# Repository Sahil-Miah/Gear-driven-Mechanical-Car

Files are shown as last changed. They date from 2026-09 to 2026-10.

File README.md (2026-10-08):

# Gear-Driven Return-to-Start Car

A front-wheel-drive car that drives down a lane to a wall, reverses, and comes back to stop where it started. It has no microcontroller. The reversing is done with a DPDT switch, and the stopping is done with a gear train and a microswitch.

This was a Year 1 group project at Manchester Metropolitan University.

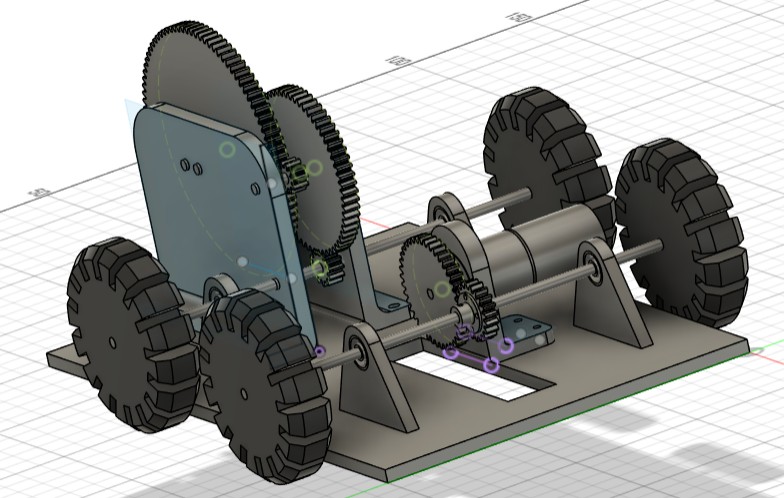
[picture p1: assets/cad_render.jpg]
CAD assembly


## Demo

[Demo video](./assets/demo.mp4). 

The car goes down a taped lane to a wooden wall, reverses, and stops on a target mat.

## How it works

### Drive

The motor is a 6V DC motor that runs at 35 RPM with no load. A 40-tooth gear on the motor meshes with a 20-tooth gear on the front axle, so the front axle turns at 70 RPM. This gives up some torque to gain speed. The rear axle isn't driven. It just turns as the car rolls.

### Reversing

A DPDT switch swaps which way the motor is connected to the battery, which makes the motor turn the other way. When the front of the car hits the wall, the front switch is hit and the motor reverses, so the car drives back. A separate on/off switch controls the power, and there is a fuse in the circuit for safety.

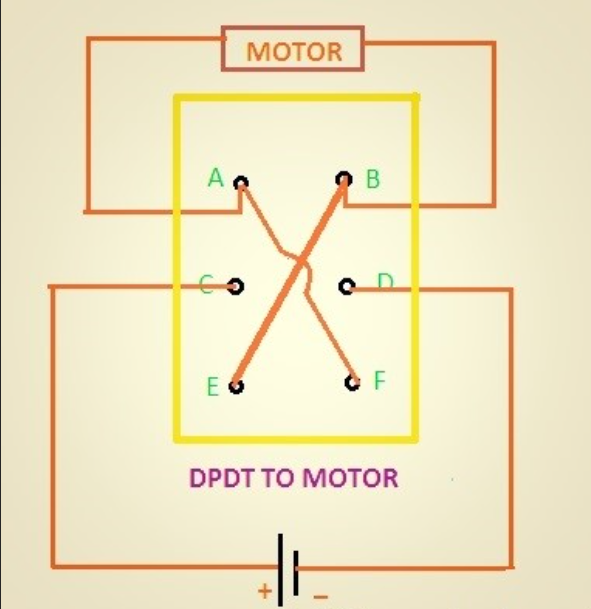
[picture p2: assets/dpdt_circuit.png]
DPDT motor reversal wiring


Diagram from electroconcepts.wordpress.com (via the module handbook), used as a reference for the wiring. It isn't our own drawing.

### Stopping at the start

The rear axle turns as the car moves, so we used it to keep track of how far the car has gone. It drives a set of gears that slows the rotation right down:

- a 12-tooth gear on the rear axle drives a 60-tooth gear
- the 60-tooth gear shares a shaft with a 10-tooth gear, which drives a 94-tooth gear with a prong on it

Overall this is a 1:47 reduction, so the prong gear turns once for every 47 turns of the wheels. It is set up to turn about 0.9 of a turn on the way to the wall. When the car reverses, the gears run backwards and the prong turns back by the same amount. When the car is back at the start, the prong hits a microswitch and cuts the power. The prong never makes a full turn, so it can only hit the microswitch at the start position.

## Calculations

We sized the drive using the method in the module's design handbook: work out the speed needed for the distance, pick a wheel size, then pick gears so the motor speed matches the wheel speed, using whole numbers of teeth.

**Drive**

- Gear ratio = 20 / 40 = 0.5, so the axle turns twice as fast as the motor
- 35 RPM x 2 = 70 RPM at the front axle
- The wheel diameter is 70 mm, so speed = π x 0.07 x 70 / 60 = about 0.257 m/s

These numbers use the no-load motor speed and assume the wheels don't slip, so the real car will be a bit slower.

**Stopping mechanism**

Both axles have 70 mm wheels, so the rear axle also turns at about 70 RPM.

| Stage | Gears | Ratio | Speed out |
|---|---|---|---|
| 1 | 12T to 60T | 12/60 = 1:5 | 70 to 14 RPM |
| 2 | 10T to 94T | 10/94 = 1:9.4 | 14 to about 1.49 RPM |
| Overall | | 1:47 | Prong gear turns once per 47 rear-wheel turns |

## Bill of materials

| Component | Qty | Notes | Cost |
|---|---|---|---|
| 6V motor | 1 | 35 RPM no-load | £9.71 |
| Wheel bearings | 4 | Smoother axle rotation | £11.00 |
| Wheels | 4 | | £0.90 |
| Rubber bands | 4 | Wheel tyres | £0.10 |
| Large gear | 1 | 5mm acrylic | £0.25 |
| Medium two-gear piece | 1 | 5mm acrylic | £0.37 |
| Small gears | 2 | 5mm acrylic | £0.18 |
| Mini gears | 2 | 5mm acrylic | £0.09 |
| Acrylic plank (26 x 10 cm) | 1 | 5mm acrylic, chassis | £1.84 |
| Axle holders | 4 | 5mm acrylic | £0.30 |
| Acrylic prong | 1 | 5mm acrylic, stopping mechanism | £0.06 |
| Steel rod (19 cm) | 2 | | £0.75 |
| Steel rod (12 cm) | 1 | | £0.24 |
| Steel rod (7 cm) | 1 | | £0.14 |
| PCB switch | 1 | DPDT reversing switch | £2.36 |
| On/off switch | 1 | Main power | £0.32 |
| Microswitch | 1 | Stops the car when hit by the prong | £0.35 |
| Fuse holder with fuse | 1 | Overcurrent protection | £0.05 |
| Batteries | 4 | | £3.32 |
| Battery holder | 1 | | £0.25 |
| Battery holder clip | 1 | | £0.25 |
| Wires | 12 | | £1.20 |
| Wall brackets | 2 | | £0.54 |
| Plastic wall piece | 1 | | £0.14 |
| Steel hook | 1 | | £1.30 |
| **Total** | | | **£36.01** |

The budget for the project was £50. The screws were standard lab hardware and aren't modelled in the CAD.

## Files

- `CAD for mechanical car.f3z`: the Fusion 360 assembly
- `CAD For Mechanical Car.step`: the same model in a format that opens without Fusion
- `Bill of Materials.xlsx`: the full cost breakdown
- `assets/demo.mp4`: video of the car running
- `assets/dpdt_circuit.png`: DPDT wiring diagram
- `assets/cad_render.jpg`: screenshot of the CAD assembly

## What we'd improve

- Add the screws to the CAD model. They're left out at the moment.
- Get the motion simulation in Fusion 360 working. It didn't run properly on our model.
- Measure how close to the start the car actually stops over several runs.

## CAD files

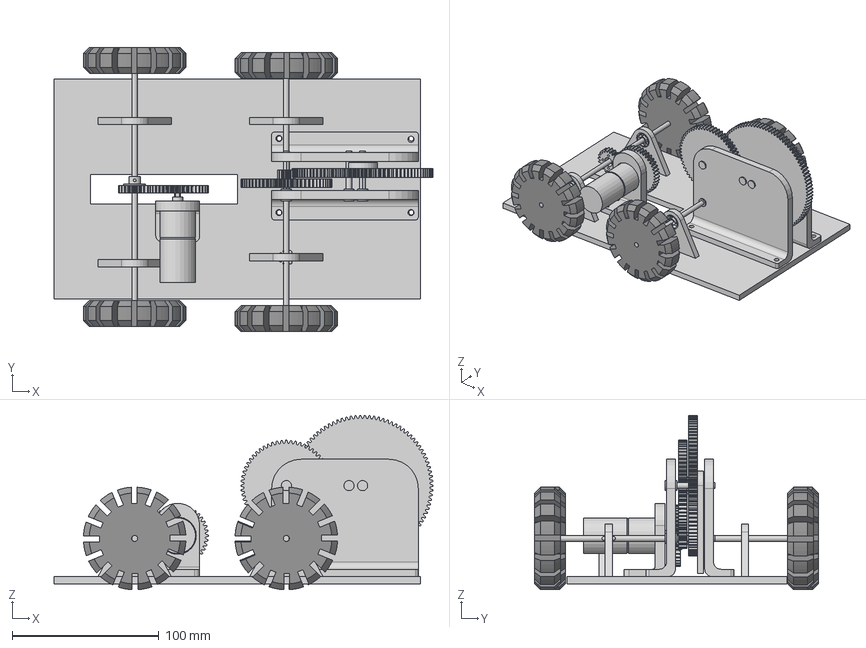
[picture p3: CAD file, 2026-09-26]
CAD For Mechanical Car.step
258.4 x 193.5 x 118.9 mm

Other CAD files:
CAD for mechanical car.f3z

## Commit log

2026-09-26 Update README with detailed project overview
    Expanded project details, including design process, calculations, and bill of materials for the gear-driven mechanical car.
2026-10-08 Revise README for Gear-Driven Return-to-Start Car
    Updated project description, added demo and design process sections, and improved clarity of technical details.
